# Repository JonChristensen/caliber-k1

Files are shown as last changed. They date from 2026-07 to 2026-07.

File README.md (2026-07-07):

# The Kelsus Manufacture — open-source, 3D-printable watch movements

**Nobody has published a working, printable, conventional watch movement designed
as a platform for complications. This project builds them — in public.**

The movements are the road, not the destination. The destination is two
complications that don't exist yet in mechanical horology:

1. **A haptic metronome** — taps your wrist at an adjustable musical tempo,
   powered by its own dedicated mainspring barrel (the architecture of
   mechanical alarm watches like the Vulcain Cricket, pointed at a new job).
   This is **Caliber K2**.
2. **A world-class tide indication** — going beyond every existing tide watch
   (Corum, IWC, CVDK all model a single tidal constituent) by mechanically
   summing a second constituent — the "priming and lagging" of the tides —
   plus perigean spring tides via an anomalistic-month cam.

Everything is **parametric Python ([build123d](https://github.com/gumyr/build123d))**:
the CAD is code, every dimension traces to a parameters file, every design
decision is a reviewable git diff, and geometry is unit-tested in CI before
any printer wastes plastic.

Like a real manufacture, this repo holds multiple calibers sharing one
engine (`movement/` — cycloidal gears, the sweep solver, the spring model):

| Caliber | What | Status |
|---|---|---|
| [**K1**](calibers/k1/) | Time + moon phase; the proven base movement | **First physical build underway** — rev C is printing; dry-train assembly next (PETG flexures to follow) |
| [**K2**](calibers/k2/) | Time + the haptic metronome | Two-sided layout frozen; winding link solved (log 0023); parts stage next |

Scale: these are desk-scale movements (Ø170 mm mainplate) — watch architecture
at a size FDM printing genuinely masters, with a metal-transferable topology
(K2's target is a 44×15 mm wristwatch case). Proven precedent: [Christoph
Laimer's printed tourbillon](https://www.thingiverse.com/thing:1249221)
(Ø102 mm, runs).

The ocean — the tide complication's destination — lives in the frame itself:
K1's train bridge is a breaking wave, and the wheels spin on whirlpool spokes.

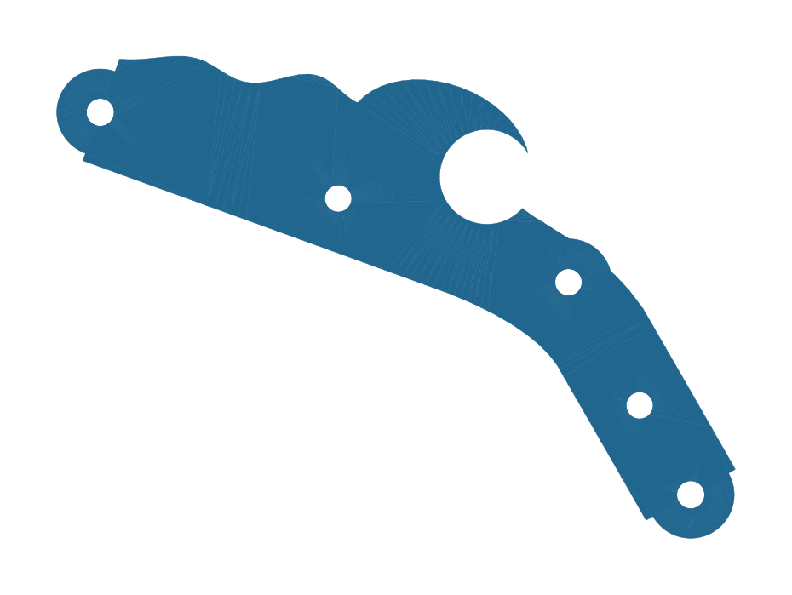
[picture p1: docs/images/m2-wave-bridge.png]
the wave bridge


## Build it

```bash
python3 -m venv .venv && .venv/bin/pip install -r requirements.txt
.venv/bin/python -m pytest tests/            # the geometry gate (runs in CI)
.venv/bin/python tools/export_print_kit.py   # K1 print kit -> exports/k1/print/
.venv/bin/python tools/render_previews.py    # PNG previews of every part
```

Print from [`exports/k1/print/`](exports/k1/print/MANIFEST.md): the MANIFEST
carries per-part orientation, support maps and quantities; the
[printing guide](docs/k1/printing-guide.md) carries the bench-proven Bambu
Studio settings. Curated, support-painted Bambu plates live in
[`exports/k1/print/plates/`](exports/k1/print/plates/README.md).

## Repository layout

- `movement/` — the shared engine: cycloidal gear generator, sweep solver,
  spring energy model. Caliber-agnostic by rule.
- `calibers/k1/` — Caliber K1 rev C: parameters, layout solver, parts, dial
  side, the traced wave bridge
- `calibers/k2/` — Caliber K2: frozen brief + metal target, the two-sided
  layout, the one-crown/two-position winding link
- `attic/` — superseded generations, kept buildable and tested: the rev A
  storey tower, the rev B flatten, K2's round-plate era
- `exports/` — print kits and review STEPs, per caliber (latest per line;
  history keeps the rest)
- `docs/log/` — the engineering journal (decisions and why), one unified
  timeline across calibers; `docs/k1/` — build guides, milestones, registers
- `tests/` — the geometry gate: clearances, mesh ratios, stack heights,
  assembled poses. CI runs it on every push.
- `tools/` — exporters and massing/review builders

## Licensing

Two permissive licenses, chosen so anyone can build a business on these
movements without asking us or paying us.

- **Hardware designs** (everything under `movement/`, `calibers/`, and
  `attic/`, plus the generated STEP/STL geometry):
  [CERN-OHL-P v2](LICENSE), the permissive variant of CERN's
  open hardware license. You can manufacture the movement, sell it, modify it,
  and keep your modifications closed. It carries an explicit patent grant, which
  a copyright-only license like CC0 or CC BY does not, and that grant is what
  protects a functional mechanical design. No reciprocity, no share-alike, no
  obligation to credit us on the movement.
- **Tooling** (`tools/`, CI): [MIT](LICENSE-MIT).

This is a deliberately more open position than the current open watch movement,
[openmovement's OM10](https://openmovement.org/project/om10/). The OM10 is
copyleft (CC BY-SA 3.0): it requires you to engrave its calibre number on the
movement, requires your derivatives to carry the same license, and reserves the
production 2D/3D data for sale under its own purchase terms. This manufacture
asks for none of that. Take the geometry, put it in a product, sell the
product, and you owe us nothing.

## Follow along

Build-in-public links (site, TikTok, videos) land here as they go live.

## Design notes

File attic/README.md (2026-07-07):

# The attic — superseded generations, kept buildable

Nothing in here is print-worthy; nothing in here is deletable. These are
the designs the current calibers were carved from, kept importable and
covered by the test suite so the record stays executable.

- **`reva/`** — K1's milestone-era storey tower (M1 going barrel → M5
  moon phase). Designed, probed, never printed as a whole: Jon's Fusion
  review flattened it into two-plate watch construction
  ([log 0009](../docs/log/0009-rev-b-architecture.md)). Its barrel frame
  (M1) WAS printed and bench-verified — the manufacture's first plastic.
- **`revb/`** — the first two-plate flatten. Every rev C part was ported
  from here ([log 0017](../docs/log/0017-rev-c-parts-port.md)); the
  print/metal variant switch it introduced now lives in
  `calibers/k1/variants.py`.
- **`k2_round_plate.py`** — K2's one-plate era: clock + metronome
  interleaved on a single round plate (massing r1–r5). The two-sided
  call ([log 0022](../docs/log/0022-k2-two-sided.md)) dissolved it.
- **`tools/`** — their exporters and mockups. `k2_massing.py` is
  stale-broken (r5-era globals) and kept only as the record of how
  `exports/k2/massing_r5.step` was made.

Old review STEPs were pruned from `exports/` (latest kept per line);
every pruned revision is in git history.

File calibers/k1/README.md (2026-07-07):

# Caliber K1 — time + moon phase (rev C)

The proven base movement of the manufacture: Ø170 two-plate construction,
6h going barrel → exactly-60-min center → 60s fourth → 30s escape (1 Hz
Swiss lever), indirect minute with a slip-collet hand-setting, moon train
on the dial side, and the traced-wave skeleton bridge as the show face.

**Status: first physical build underway (July 2026).** Mainplate, wave
bridge, barrel/winding group and the train + escapement set are printed;
dry-train assembly is next. The PETG flexures (mainspring, hairspring,
click, transfer pinion, stem clip) close the build after that.

## Where things are

- [`parameters.py`](parameters.py) — every dimension in the caliber
- [`revc.py`](revc.py) — the whole-movement model: z-grammar, layout
  solver, sweeps, the check_all gate (K1's binding of `movement.solver`)
- [`revc_parts.py`](revc_parts.py) / [`revc_dial.py`](revc_dial.py) /
  [`revc_dial_parts.py`](revc_dial_parts.py) — movement side and dial side
- [`variants.py`](variants.py) — the print/metal variant switch
  (`K1_VARIANT=metal` reflows the movement)
- [`gears.py`](gears.py) — TRAIN-default binding of the shared cycloidal
  engine

## Build artifacts

- Print kit: [`exports/k1/print/`](../../exports/k1/print/MANIFEST.md)
  (regenerate: `python tools/export_print_kit.py`)
- Printing guide: [`docs/k1/printing-guide.md`](../../docs/k1/printing-guide.md)
- Review STEP: `exports/k1/revc/movement_r11.step`
  (regenerate: `python tools/build_revc_movement.py`)

Earlier generations (the rev A storey tower, the rev B flatten) live in
[`attic/`](../../attic/) — buildable, tested, superseded.

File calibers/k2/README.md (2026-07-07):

# Caliber K2 — time + the haptic metronome

A TWO-BARREL caliber: K1's proven time core as the base, plus the
metronome as its complication — 60–180 BPM continuous (variable-inertia
balance with sliding weights), hammer tick + desk thump, chronograph
pen-cam pusher, its own barrel with a ≥30-min-at-180 beat budget.
The frozen brief is [log 0020](../../docs/log/0020-metronome-brief.md).

**Architecture of record: TWO-SIDED** (Jon's call, July 5 2026 — the
chronograph-module pattern). Base time movement on one plate, metronome
module stacked toward the caseback on its own full-diameter plate, both
Ø166. One crown, two positions: push winds the base, pull winds the
module through a riser + cross-plate transfer
([log 0023](../../docs/log/0023-k2-winding-link.md), SOLVED).

**The metal target governs**: K2 must eventually drop into a ~44×15 mm
wristwatch case (Ø40×10 movement). The print and the metal are one
topology at two scales.

## Where things are

- [`brief.py`](brief.py) — the frozen brief, metal target, energy
  budget, tooth counts
- [`layout.py`](layout.py) — the two-sided layout, module solve, Jon's
  full-cast inventory, K2's mesh-pair registry
- [`winding.py`](winding.py) — one crown / two positions: sweeps, solver,
  and the cross-plate gate

Massing artifact: `exports/k2/two_sided_r2.step`
(regenerate: `python tools/k2_two_sided_massing.py`).

**Status:** massing at Jon's gate; parts stage next. The superseded
one-plate interleave (massing r1–r5) is in
[`attic/k2_round_plate.py`](../../attic/k2_round_plate.py).

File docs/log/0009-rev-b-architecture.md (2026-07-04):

# 0009 — Caliber K1 rev B: the flattening (plan of record)

Jon's Fusion review of the rev A assembly found the truth: a 2.7:1 tower
built by accretion around the M1 test fixture. Rev B rebuilds the SKELETON,
keeps the ORGANS. Approved July 3, 2026.

## Architecture (classic two-plate watch construction)

- **Mainplate** Ø170 + individual **bridges** on top: barrel bridge, train
  bridge (THE WAVE — finally visible as the movement's crown), balance
  cock (jewel over the wave tube, per the 0003 contract, now on display).
- **All wheels interleave into 2-3 gear planes** between mainplate and
  bridges. Target overall height ~24mm => 4.2mm at Ø30 metal scale (OM10
  proportions). Every milestone gets a "would this ship in metal?" review.
- **Offset barrel** (not center). **Winding from the edge**: crown-style
  stem or edge key — never through the movement's face.
- **Center wheel at center** if spring physics allows a classic train;
  otherwise document the deviation as print-era with the metal train
  designed alongside (both ratio sets tested).
- **Escapement**: Swiss lever club-tooth as the DESIGN escapement (metal
  target); pin-pallet kept as the printable fallback variant. Both from
  one parametric generator, selected by a parameter.
- **Display**: hands on the front at proper heights (no storeys), moon
  aperture in a dial sector. Module bay preserved (interface v0 carries).

## What transfers unchanged (the organs)

gears.py (cycloidal generator) - decor.py (wave, swirls, tube contract) -
tools/solve_m4.py pattern (extend into a general placement solver) -
oscillator physics + trim math - moon train (14->63|8->105) - module
interface contract - all test discipline - Milestone 1 barrel INTERNALS
(spring, arbor, ratchet, click — the drum becomes offset).

## What dies

The spider plate (test fixture, never architecture). The deck plate, dial
cock, and storey stack. Center-through winding square + knob. The M1
stand plates remain only as the historical barrel test rig.

## Execution order

1. rev-b/ layout: gear-plane assignment + solver run for the full flat
   train (barrel, center, W3, W4, escape, balance, motion works UNDER
   the dial side — the watch way).
2. Mainplate + bridges (wave bridge = train bridge, visible).
3. Escapement generator (lever variant) + balance over the wave.
4. Motion works + hands + moon module in-plane.
5. Renders reviewed in Fusion BEFORE each milestone freezes.

## Status correction (Jon's catch, post-2e-half)

r6 has NO pallet lever — "mechanically complete" was an overclaim. Built
and verified: full going train (phase-aligned mesh proofs), pallet cock,
pallet arbor layout + pins, balance staff/ring/hairspring seats. Missing:
the lever itself (rev A's is welded to tower geometry) and the roller's
rev B seat. Escapement remains variant-triggered per the plan:
print=pin_pallet (tolerance-tolerant, proves the runner), metal=
swiss_lever club-tooth (DFM pass, machining tolerances) — including the
matching escape-wheel pair (pointed vs club teeth). Next mechanical work:
port the pin-pallet lever + roller onto escapement_layout_b.

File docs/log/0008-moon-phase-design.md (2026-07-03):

# 0008 — Moon phase: drive point found, storey decision pending

Findings from M5 geometry kickoff:

1. **M4 bug found & fixed**: the hour wheel's Ø9 pipe collided with the
   dial cock's Ø6.4 bore. Cock bore opened to Ø9.4 — the pipe now journals
   in the cock (a feature: extra hour-wheel steadiness). Hands stack shifts
   up ~3mm in the next export pass.
2. **Moon drive**: a 14-leaf pinion integral with the hour pipe, ABOVE the
   cock (z~56+, open sky). The committed 46/9x104/9 ratios assumed a 9-leaf
   pinion that cannot exist on a Ø6.8-bore pipe (zero root depth) — ratios
   must be re-searched with s1_pinion=14 (target (A/14)(C/d) = 59.061176).
3. **Moon train runs module 0.8** (display torque only): the 104t-class
   moon disc shrinks to ~Ø85, which fits the rim with center <= r40.
4. **Open decision**: the moon disc plane vs hands sweep — either the disc
   flies above the minute hand (tower grows ~5mm) or the classic move: a
   fixed DIAL ring over the works with the double-hump moon aperture, hands
   above the dial. The dial option is more watch, less tower. Recommended.

Next: re-run ratio search (s1=14), model disc + s1 arbor + moon cock +
aperture dial, module clearance tests. The module mounts on the dial cock
+ one deck pillar — the module bay's first tenant.

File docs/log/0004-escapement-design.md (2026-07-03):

# 0004 — Milestone 3: the escapement storey

Pin-pallet lever escapement above the wave bridge; balance centered on the
wave tube per the 0003 contract. Key numbers: pallet arbor 16.5mm from the
escape arbor (pins subtend 3.5 tooth spaces, engage 1.6mm); fork 20.7mm;
balance Ø50 at 1 Hz; hairspring 11 coils × 0.45mm PLA, predicted T=1.037s.
Physics lives in parameters.py (balance_inertia, hairspring_stiffness,
predicted_period) — CI fails if the oscillator drifts out of the nut-trim
band. Plate grew to Ø170. Platform stands on two plate-rooted pillars after
the clearance test caught bridge-mounted legs inside the escape wheel sweep
(center-distance checks lie; radii matter).

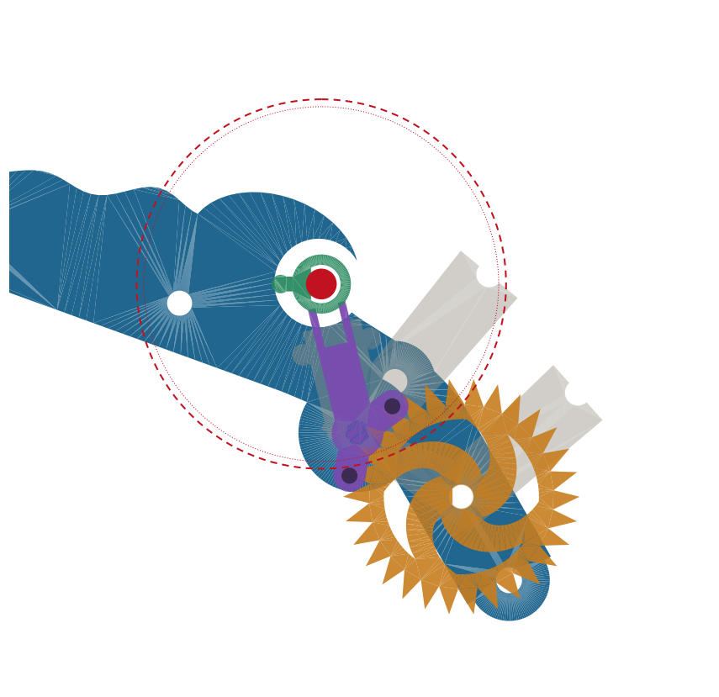
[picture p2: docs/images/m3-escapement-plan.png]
escapement plan


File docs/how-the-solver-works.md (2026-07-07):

# How the rev C layout solver works

*(Plain-English companion to `caliber_k1/revc.py` — the code is ~80 lines;
this is the idea behind them.)*

The solver in three pictures

## The trick that makes it all possible: forget the tooth shapes

A gear is a complicated shape, but the moment it *spins*, it occupies a
simple cylinder — a can. So the solver never looks at teeth at all. Each
part becomes five numbers: where it sits (x, y), how fat it is (radius),
and which heights it spans (bottom z, top z). That's a `Sweep` — the whole
movement is about twenty cans.

The payoff is that "do these two parts ever touch, at any rotation, at any
moment?" collapses to grade-school math: **if two cans share any height,
the distance between their centers must beat the sum of their radii plus
2mm of air.** Distance between centers is the Pythagorean theorem. One
subtraction, one square root — millions of checks per second, where asking
the CAD kernel to intersect two toothed solids takes about a second each.

## Two escape hatches make it a watch instead of a parking lot

1. **Gears that are *supposed* to touch** (meshing pairs) are on a
   whitelist — the can test skips them, and their tooth-by-tooth
   engagement is proven later by the slow, accurate CAD probes
   (`tests/test_revc_parts.py`), run once instead of millions of times.
2. **Cans only conflict if they share height** — the shelf system. The 80t
   minute wheel flies right over the barrel because it's on shelf B and
   the drum tops out below it. Watchmakers have exploited this for three
   centuries; the solver gets it as a rule.

## The search is a compass walk

Meshing gears must sit at an *exact* center distance — the minute wheel
belongs precisely 35mm from the barrel. So its position isn't free; it's
somewhere on a circle. The solver puts the barrel down, swings a compass
around it, and tries 36 spots (every 10°). Each survivor gets a new
compass swung around *it* for the next wheel, and so on down the chain:
barrel → minute → third → fourth → escape → balance. Six nested compasses.

## Pruning is why it finishes before we retire

Naively that's 36⁵ ≈ sixty million layouts. But the moment a candidate
spot crashes into anything already placed, the solver abandons it **and
every layout that would have been built on top of it** — millions of dead
branches lopped off with one failed subtraction. It's how you solve a
maze: you don't map the whole dead end, you turn around at the wall.
Survivors get scored, and the winner is the layout whose farthest part
edge stays closest to center — the most compact watch that breaks no rules.

## The one weakness — and it bit us twice

The solver only knows what the cans tell it. The pallet fork isn't
remotely can-shaped (it's a rocking arm), so we approximate it with two
circles covering its full swing. When those circles were drawn too small,
the solver cheerfully approved layouts where the *real* fork poked into
the *real* plate. Both "unsolvable!" panics and one genuine collision in
this project traced to dishonest cans — never to bad math.

That's why the pipeline is belt-and-suspenders:

| stage | speed | what it proves |
|---|---|---|
| can test (`check_all`) | millions/sec | placement never collides, at any rotation |
| tooth probes (phase-aligned) | ~1 sec each | meshing gears engage without jamming |
| assembled-pose gates | ~30 sec total | the exported STEP itself is clean |

The cans buy speed; the probes keep them honest.

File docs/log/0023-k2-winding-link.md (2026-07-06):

# 0023 — K2 winding link: one crown, two positions across two plates

**Date:** 2026-07-05 · **Status:** open design problem, scoped

Two-sided K2 (log 0022) leaves one real sub-design: how one crown winds
**both** barrels when they sit on different plates. Position 1 (push)
winds the base barrel via K1's existing winding — reused, done. Position
2 (pull) must wind the **module** barrel, and that's the hard part.

## The constraint the gate surfaced

The module barrel is big (76t, r38) and central, so its ratchet sits at
the module-plate **center**, at bridge z (~34–36). Reaching it from a
base-level north crown is NOT a straight shot:

1. stem enters the north rim at base level (z~13)
2. a **vertical riser** climbs ~22mm to module-bridge level — and must
   clear both drums (r38), so it rides the **flank** of the module drum
   (there's only 9mm north of the drum, but 48mm+ to the sides/south)
3. a **horizontal transfer wheel** at module-bridge level runs inward
4. → the module crown wheel → the module ratchet

Plus the shared clutch + setting lever + detent that select position 1
vs 2. First naive hand-placement collided (riser through the drum, clutch
crammed north) — a clear sign this needs its own solve, not patching.

## Plan

A small dedicated solver for the winding link: riser azimuth free around
the drum flank, transfer-wheel placement gated against the module train,
clutch works spaced along the stem. Reserved coarsely now
(`winding_link_zone`) so the massing shows the space; geometry at the
solve. Everything else on the module plate is gated clean.

## Update (same day): position 2 SOLVED

A focused `solve_winding_link` (search the riser azimuth for a channel
clear of both drums, place the module crown wheel on the line to the
ratchet, transfer + clutch). First objective (minimize plate reach)
threaded a 70mm train up the south channel — valid but absurd. Re-aimed
at **shortest winding path**: found the NE flank, **44.5mm**, one crown
at ~2 o'clock → riser (40.9, 50.5) up the drum flank → transfer →
module crown wheel (19.9, 41.5) → module ratchet. Clean against both
plates (`k2_winding_gate`, `test_k2_winding_position2_clean`).

Key fix: the keyless cluster (clutch/setting/detent/riser) interlocks —
the 2mm inter-part rule is wrong for a coupled mechanism, so those pairs
are whitelisted (verified by the part-level probe later, like the
escapement).

**Position 1 (base) remains:** winding the base barrel from the same NE
crown needs a multi-wheel base-level train that dodges K1's SE click
(the short paths collide). Pending tier: `cw1_core`, `m_stem`,
`wind_base`, `wind_xfer_base`. Not the novel part — ordinary keyless
routing — but real, and left honest rather than faked.

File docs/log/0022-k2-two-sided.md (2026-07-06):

# 0022 — K2 goes two-sided: the plate stops growing

**Date:** 2026-07-05 · **Decision:** Jon — "two-sided metal module."

Jon chose the chronograph-module architecture: base time movement +
metronome MODULE stacked toward the caseback, not side-by-side on one
plate. This **dissolves the O250 frankenplate problem** — the two
movements no longer compete for one plane, so each gets its own
full-diameter plate. K2's plate returns to **Ø166 (same as K1)**.

## The stack (front → back)

crystal · dial + hands · motion works · **base plate** · base going
train + escapement + balance + base bridge · **module plate** ·
metronome works + hammer + variable-inertia balance · module bridge ·
display-back crystal.

- **BASE** = K1's proven time core (revc) verbatim, minus the moon train.
  No re-solve — it's K1.
- **MODULE** = the metronome ALONE on its own Ø166 plate. Solved
  (`solve_module_alone`, 123s) to reach 63.8 of 83 — 19 mm of margin, a
  roomy single-cluster layout like K1's clock, not a desperate interleave.
- One crown, two positions winds the two barrels (push = base, pull =
  module).

## Numbers

Print: Ø166 × ~36 mm (two movements stacked — a tall desk model, fine).
Metal: Ø40 × ~6 mm scaled, but the z-table is variant-tall → fits the
~10 mm case budget with room. The metronome, its balance and hammer,
show through the sapphire display back.

## Status

`k2_module_gate` CLEAN; the full inventory (log 0021) rides the module
plate. Next: the base↔module winding link (one crown, two positions),
the module-plate pillars down to the base, and Jon's massing gate on the
two-sided stack. Then K2 parts — the variable-inertia balance and hammer
first (the two mechanisms K1 doesn't already prove).

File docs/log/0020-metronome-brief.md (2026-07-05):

# 0020 — M6 brief: the haptic metronome module

**Date:** 2026-07-05 · **Status:** requirements frozen (Jon), mechanism
concept chosen; massing + solve next

## Jon's requirements

- **Tempo: 60–180 BPM, continuously adjustable** (3:1 range)
- **Beat: hammer tick + desk thump** — hear it AND feel it through the desk
- **Start/stop: chronograph-style pusher** — press to run, press to stop
- Own barrel (independent of the timekeeping train), winds like the clock

## The mechanism concept

**A variable-inertia balance.** The movement lies flat, so gravity
pendulums (Maelzel-style) are out — the oscillator must be a balance +
hairspring, which is orientation-free. The 3:1 tempo range is the hard
part: rate ∝ √(k/I), so a 3:1 rate span needs a **9:1 inertia span** —
far beyond regulator pins. The answer is horologically delicious: **two
weights sliding radially in the balance arms** (r≈5→15mm gives the ~9:1
on the dominant inertia term), driven symmetrically by a lead screw or
scroll cam through the **tempo knob**. A Gyromax taken to its logical
extreme — the tempo dial literally moves the balance's mass outward for
largo, inward for presto.

- Oscillator: 0.5–1.5 Hz (beat = 2/period = 60–180 BPM)
- Escapement: our proven club wheel + Swiss lever, module-scaled
- **Hammer**: pin wheel on the escape arbor lifts a weighted hammer that
  drops on the mainplate/base — one strike per beat, tick + thump
- **Pusher**: pen-cam (retractable-ballpoint) two-state toggle pressing a
  brake finger onto the balance rim; press-run, press-stop
- Tempo calibration: engraved BPM arc under the knob, bench-calibrated

## Reality check on space

The reserved module bay (r18 at (56,18)) holds a barrel OR the
oscillator, not both plus a hammer and pusher. Expect the module to
claim the whole eastern sector, possibly as its own **module plate**
above the bridge band (the massing will decide honestly). The module
interface (0004) still governs: the metronome must mount/dismount as a
unit.

## Next steps (massing-first, as always)

1. Station list + sweeps: m-barrel, m-train (2 wheels), variable
   balance (its sweep grows with the weights OUT), lever, hammer arc,
   pusher line, tempo knob.
2. Energy model: beat torque for an audible strike × runtime target
   (≥30 min practice session per wind? Jon to confirm).
3. Solve the module layout in/over the east sector; massing render;
   Jon's gate; then parts.

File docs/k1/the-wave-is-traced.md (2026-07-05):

# The wave, traced

The bridge decoration is TRACED from `art/wave_reference.png` (Jon's
mockup), not hand-drawn. Pipeline: `tools/trace_wave.py` classifies the
image into blue-plate / white-gap / gray-rim, finds the disc, and turns
each white wave-gap into a millimetre polygon in `art/wave_traced.py`.
`revc_parts.traced_wave_faces()` subtracts those polygons from the bridge
with structural keep-outs removed first, so the art can never cut a
load-bearing feature.

## To change the wave
1. Edit the mockup image (any tool), keep it a blue plate with white
   wave-gaps and a gray rim, save over `art/wave_reference.png`.
2. `PYTHONPATH=. .venv/bin/python tools/trace_wave.py [rotate_deg]`
3. Rebuild — the new curves flow straight through to the STL.

An SVG-path pipeline (draw the curves directly in a vector tool) is a
small addition if pixel-tracing ever loses fidelity.

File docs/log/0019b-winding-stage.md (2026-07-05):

# 0020 — The winding stage: crown to ratchet, nothing above the bridge

**Date:** 2026-07-04 · **Status:** movement_r5.step (40 components), 82 green

Jon's massing r6 gate passed and the winding parts landed. The mechanism
settled one level simpler than the massing sketched: no tall-core crown
wheel — the 6498-true arrangement cuts 23 bevel slots into the crown
wheel's UNDERSIDE and the stem's 7t pinion meshes them FROM BELOW (rev
B's proven face-slot pair, flipped: the height cost becomes a height
savings). Stem axis z12.8 in the corridor; the crown never rises above
the bridge; the drum_gear x stem whitelist is justified by an analytic
clearance test (pinion swept cylinder to drum tooth tips: 2.85 >= 2.0).

Parts: crown_wheel_c (24t spur + underside slots, flush in the bridge
pocket), crown_stud_c (shoulder stud, press tail in the web),
stem_c (one print: fluted crown, tunnel body, clip groove, pinion),
stem_clip_c (printed C-clip). Bridge grew the crown pocket + stud bore
+ the tunnel boss (case-tube analog). The slot ring spans the pinion
tip's full chord (first cut grazed solid wheel beyond short slots —
the engagement-profile probe found it: 0 at settled roll, 1.4 mid-rib).

Winding: ~9 crown turns for the full ~17h wind (23/7 x 24/24 x 2.78
turns). Setting: still push-the-hands (transfer collet slips); the
pull-to-set clutch is the future keyless refinement, and the stem is
now at the right level for it.

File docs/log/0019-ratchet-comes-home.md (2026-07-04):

# 0019 — The ratchet comes home: Jon's NH35 catch re-solves the movement

**Date:** 2026-07-04 · **Status:** massing_r4 + movement_r3 exported, 80
tests green, verification-fleet findings applied

Jon flagged the dial-side ratchet poking into the dial's airspace and held
up the NH35: the ratchet belongs on the MOVEMENT side. He was right, and
the diagnosis went deep: the dial-side winding was a patch on a patch —
the 80t minute wheel overhung the barrel center, which decapitated the
barrel arbor at z11, which forced the hanging barrel, which forced
dial-side winding.

## The root fix: new tooth counts

`(60, 10, 56, 7, 45, 6, 36, 18)` — worked out under four simultaneous
constraints (all now encoded in the solver's menu comment):

- minute wheel ≤ r29 so the **barrel arbor column** (a new permanent
  sweep the global gate protects) rises past plane B to the bridge;
- minute PINION small enough that it clears the coplanar third wheel —
  which forced the drum to 60t/10-leaf = **6h per turn**, and the bigger
  drum holds more spring: runtime IMPROVES to **~17h** (from ~10);
- the barrel stands off at y ≥ 40 (a dial-side reservation: the moon
  pinion's pocket needs 10.7 of drum-free plan at the origin);
- (56/7)(45/6) = 60.000 — timekeeping exact, as always.

## What the architecture becomes

- **Two-bearing barrel**: plate cup below, bridge-web bearing above. The
  hanging-barrel wobble flag from 0017 dies.
- **Ratchet + click recessed FLUSH in the bridge top** (the NH35
  composition), click pegs through the bridge web, winding by key into a
  **female square socket** — nothing stands above z17.7.
- **The dial face is completely untouched** — no bore, no boss, no pegs.
  The dial sheet reservation is now a constant (`DIAL_SHEET`).
- Transfer chain slimmed to 10-24-24-10 (the pinion pocket must fit
  between the minute arbor and the drum recess — 0.8mm of margin).

Both solvers re-ran (bridge 70s, dial <1s after teaching the i2 ring to
walk at 1/3 step — its legal windows are ~7° wide). Same-day fleet
findings folded in: feature-aware post bores (the disc post would have
breached the bay floor — posts are now IN the gate), posts extended to
z-0.7 as platform supports/locators (dial-feet analog), cannon/hour pipe
walls thickened, the transfer collet got a doubled flexure hub, press
bores derive from `Variant.press_r`, and a platform-coverage retention
test. Interim hand-setting: push the minute hand; the transfer collet
slips (the keyless stage adds the proper setting path).

## For Jon's gate

`exports/revc/massing_r4.step` (composition moved: train now sweeps the
WEST side, balance at ~5 o'clock, moon window lands near 6) and
`exports/revc/movement_r3.step` (36 components). The stack still tops at
17.7; the dial side is clean glass.

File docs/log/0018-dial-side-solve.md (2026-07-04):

# 0018 — The dial side: four depth bands, three hard theorems, one solver

**Date:** 2026-07-04 · **Status:** movement_r2.step (36 components), 79 tests
green, dial verification fleet run before Jon's gate

The dial side got the same treatment as the massing: a whole-face model and
solver (`caliber_k1/revc_dial.py`) BEFORE any geometry, because rev C's
compactness makes the plate's underside a minefield — the drum recess floor
sits 2.2 above the dial face with its plan edge 12mm from center, the bay
allows 2.8, bushings 2.9, strap pilots 1.9. Every pocket obeys
`depth ≤ local ceiling − 0.6`, enforced by `check_dial()` forever.

## Three theorems the solve surfaced

1. **The 1:1 transfer can't be a pair.** A direct pair needs two r13+
   wheels; the cannon-side one would overhang the drum plan where only 1.6
   of depth exists. It became a 16-24-24-16 **idler chain** — every member
   deep-band legal, and the odd mesh count keeps the hands clockwise (the
   full chirality chain from the club-tooth lean to the cannon is documented
   in the module docstring).
2. **The axis theorem.** The hour pipe surrounds the cannon, so the cannon's
   gears must sit ABOVE the hour pipe's top. That forces a SHORT hour pipe
   with the moon pinion riding LOW (B2) — which also dissolved the
   motion-wheel/moon-wheel fight for the southwest plate.
3. **A two-stage moon train is impossible here.** Any wheel meshing a pinion
   at the origin lands its rim at d/(1+ratio) from center; the cannon needs
   7.8 clear, and 59.0625 split two ways forces ratio ≥ 4.2 → rim at ~4.
   (Rev B carried this collision silently — the gate caught it.) The moon is
   now THREE gentle stages: (36/24)(54/12)(70/8) = 59.0625 exactly, still
   29.53125 days, 1 day per ~122 years.

## What's in the face (frozen `DIAL_LAYOUT`, reach 64.3 of 83)

Motion works south (12:1 exact, module trick at d=24); moon train sweeping
west, disc at 10–11 o'clock with the platform window over its r13.5 orbit;
transfer chain in the western corridor. Parts: Ø3 center post + five Ø2
arbor posts (register pins), cannon, hour wheel + integral moon pinion,
motion arbor, w1, w2, moon disc (moons recessed 0.25), wheel-form idlers
(pinion-form idlers only kissed noses — proper cycloidal pairing is
wheel-drives-pinion), and the retaining platform.

## Design corrections the gates forced

- **Backlash scales with module** (0.3·m): the flat 0.3 tuned for m1 train
  teeth would eat half a m0.6 tooth.
- **Hand setting**: the chain rigidly geared the cannon to the train — no
  way to set the time. The transfer pinion now friction-grips the minute
  arbor's round stub via a slit collet (the hairspring pattern): running
  torque carries, setting torque slips. The keyless stage builds the
  setting input on top of this slip.

## Open items

- Keyless works (winding conversion from the dial-side square + setting).
- The wave pass (2f) over the now-complete movement.
- Metal-variant escapement retune (tracked skip, see 0017).

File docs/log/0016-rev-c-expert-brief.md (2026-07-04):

# 0016 — Rev C: the expert brief (end of the patch loop)

Jon's diagnosis, accepted: rev B was rebuilt by accretion under user
correction — locally-right patches, globally-wrong architecture. Rev C
is designed top-down, whole-movement-first, by the numbers below.
No part gets modeled until the layout study passes the global test.

## Hard targets (print variant / metal variant)
- Total stack **<= 28mm / <= 14mm** including cock, excluding crown.
- **Two gear planes + one escapement plane.** No arbor longer than 18mm.
- Drum **<= 35% of plate diameter** (<= O60 on O170). Recover energy by
  wider-flatter spring or accept 4-6h print runtime (bench duty).
- Barrel position becomes a FREE variable in the layout solve: if the
  drum cannot coexist with a central center wheel, use an intermediate
  transmission wheel (classic solution) or offset time display.
- Stem at PLATE level; true keyless works (winding pinion, clutch,
  setting lever, yoke) in the dial-side pocket; crown fully outside the
  plate boundary. Crown wheel + ratchet stay celebrated on the bridge.
- Oscillator: Jon's arrangement is KEPT (it converged on real watch
  practice): ring under bridge in the well, spring nested in the well
  thickness, near-coplanar cock, removable pallet bridge, steel staff,
  bushings/thrust shims per the parts register; jewels in metal variant.
- ONE broad bridge (the wave) + balance cock + pallet bridge. Nothing else.

## Process discipline (the actual fix)
1. **Global swept-volume test FIRST**: every rotating part declares its
   swept cylinder (r_tip, z-band); one test asserts all pairwise
   rotating-vs-rotating and rotating-vs-static clearances across the
   WHOLE movement. It exists before any rev C part is modeled and gates
   every commit. No more pairwise patches.
2. Layout study: solver over ALL stations simultaneously (barrel free,
   train, oscillator, keyless, motion works) against the swept-volume
   model + energy model. Deliverable: one massing STEP for Jon's gate.
3. Only after the massing gate: port parts (all generators survive).
4. Jon's role returns to taste and bench truth; whole-movement
   consistency is the designer's job — mine — enforced by the global
   test, not by his screenshots.

Rev B stays in-tree: every generator, probe, register, and lesson
carries forward. The layout does not.

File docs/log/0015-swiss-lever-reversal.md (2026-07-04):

# 0015 — The Swiss lever reversal (Jon's AliExpress evidence)

Jon gently pushed back on "a Swiss lever can't print": his AliExpress
tourbillon visibly has a pallet fork. Verified — he is right:

- Laimer (thing:1249221, our scale ancestor): "The watch has a Swiss
  lever escapement." Anchor 100% printed PLA (0.06mm layers, 80% infill),
  no jewels, runs at Ø100mm — smaller than K1.
- The Mechanica clone family (Jon's unit): printed "Escape Fork" with
  named left/right pallets; runs; known overbanking mode fixed by longer
  fork horns (designer ships a tuning variant + STP).
- Design rules (Headrick/abbeyclock, NAWCC, funprints4u): LOCK 2-3 deg
  for print (+-0.15mm error ~ 1 deg of lock at Ø32 wheel; watch practice
  1-2 deg eaten entirely by print error), DRAW textbook 12-15 deg (no
  more — unlocking losses), flat faces, generous horns, banking pins.

## Decision

Escapement PARITY: swiss_lever in BOTH variants — angles per variant
(print: lock 3.0/draw 15.0; metal: 1.5/13.0). Pin-pallet demoted to
fallback (code retained). The print bench now rehearses the metal
escapement's architecture — the variant switch fulfilling its purpose.
Next build session: parametric lever generator (lock/draw/lift from the
variant), club-tooth escape wheel pair, fork horns sized per the
Mechanica overbanking lesson, phase-aligned probe like the train's.

Full sources in the research transcript; key: makezine tourbillon
tutorial, thingiverse 1249221, myminifactory Mechanica guide,
abbeyclock lever construction.

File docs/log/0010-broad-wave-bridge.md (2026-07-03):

# 0010 — The broad wave bridge (Jon's NH35 correction)

Vocabulary bug found by Jon: "bridge" meant a narrow finger bridge to me,
but the NH35-style BROAD train/barrel bridge to him — the wide decorated
plate that covers the movement's back and defines its face. He is right:
that is the showpiece, and it is also better engineering.

## Revised step 2b (supersedes the narrow band bridge)

- ONE broad bridge covers barrel + train: upper bearings for barrel,
  center, third, fourth, escape in a single plate (z16-19). Replaces
  three planned parts. Feet become a bolted perimeter, NH35-style.
- Large round BALANCE OPENING (~Ø54): the balance swims visible in its
  own well; balance cock spans the opening; staff upper bearing + cap
  jewel in the cock. The enclosed-tube-as-bearing idea is retired — the
  open-mouthed rev A curl returns at the opening's rim.
- Art direction (Jon): the crest breaks AWAY from the balance — the
  balance emerges from the wave into calm water. Serenity over drama.
- Surface finishing pass later: printed Cotes de Geneve — literal
  "Geneva waves" striping flowing in the swell direction.
- The narrow wave_bridge_b stays in git history as a study.

Inspection gate for the rebuild: exports/revb/wave_bridge.step over the
massing — swells legible at arm's length, curl open at the balance well,
five bearing bosses over their arbors, stem sector untouched.

## Print-vs-metal deviation register (running)

- Stem line at z29.5: forced by the 20.5mm printed drum the stem must
  overfly. Metal variant: ~5mm barrel, stem drops to plate level
  (NH35-style). Crown moved to r88, overhanging the plate edge with
  >=0.5mm proven clearance to the bridge's north edge.

## 0012-in-place: the variant switch (Jon's clean-flip requirement)

Variant is now a first-class build parameter (revb.VARIANTS, K1_VARIANT
env): print and metal share every coordinate and tooth count; they
differ only in dimension TABLES (drum height, clearances, spring,
escapement type), and derived values like the stem line are FORMULAS
of the variant — flip the switch, the movement reflows. Migration plan:
every part function gains variant-awareness as it is next touched; CI
will build and test BOTH variants; exports split into
exports/revb/{print,metal}/. The CNC drawing will be the metal variant
of the same tested code — never a translation.

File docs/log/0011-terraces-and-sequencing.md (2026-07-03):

# 0011 — NH35 bridge study: terraced relief + design-the-cover-last

Jon supplied the isolated NH35 decorative bridge. Two adopted lessons:

1. **The wave should be TERRACED, not outlined.** The NH35's waves are
   stepped crescent plateaus in z — light catches each step edge. Rev B
   swells become three relief terraces (~1mm steps) cascading toward the
   balance well; the crest is the tallest terrace curling at the rim;
   the well may open into a C like the NH35's. Sunburst/Geneva graining
   flows across terraces in the finishing pass. Prints and mills cleanly.

2. **Sequence: pack the movement first, sculpt the cover last.** The
   bridge's mechanical interfaces are frozen and tested (5 bearings,
   well, feet). Its OUTLINE and terracing wait until everything under
   it exists: balance cock, escapement, keyless works, dial-side moon.
   Revised order: 2c balance cock + escapement -> 2d keyless works ->
   2e motion works + moon (dial side) -> 2f THE BRIDGE beauty pass with
   the full movement packed -> Jon's gate on the complete composition.

## Correction (same day, Jon's second photo)

The NH35 bridge is NOT terraced — it is a FLAT plate. The "steps" were
Cotes de Geneve striping (sub-mm surface finishing) whose grain-direction
changes read as depth in the first photo. Revised guidance for 2f:

- The plate stays flat (simpler to print, simpler to mill — and true to
  the reference). The wave lives in (a) the sculpted OUTLINE and
  cutouts, and (b) shallow striping: ~0.3mm printed relief bands
  (one layer step) flowing as wave-front crescents toward the well —
  our Cotes de Geneve, literally waves.
- Real z-terracing remains available as a deliberate K1 signature move,
  but it must be chosen as OUR aesthetic, not misattributed to the
  NH35. Decision deferred to the 2f beauty pass with the movement packed.
- Sequencing lesson (pack first, sculpt the cover last) stands unchanged.

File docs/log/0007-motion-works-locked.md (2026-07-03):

# 0007 — M4 layout locked: every arbor placed, every clearance tested

Final restack after tests caught two more real collisions (R1's Ø34 wheel
cannot pass the foot_a/cock gap — max gap supports Ø26; first R2 branch sat
in the winding-knob sweep and balance ring):

- Ratios: (24/16)(32/10)(30/10) = 14.4 exact; 12:1 motion works. Tested.
- R1 24t at (-9.65,-58.23) z10.5-15.5, climbing pinion to the deck.
- R2 32t at (11.27,-56.49) — computed circle intersection, outboard branch.
- T (dial center) at (14.8,-36.8); M at (38.8,-36.8); hands at z56.
- Deck plate z28.2 on pillars (57,-17) and (2,-79); dial cock z52.5.
- CONSEQUENCE: the T-handle winding key is retired; M5 models a low-profile
  winding KNOB (Ø44, sweep r<=23.5 enforced in test_m4_deck_clearances).

Remaining M4 modeling (no unknowns): r1/r2/t/m arbors, deck plate, dial
cock, friction cannon, hands, knob — next session, then M4 prints.

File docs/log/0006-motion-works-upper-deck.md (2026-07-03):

# 0006 — Motion works: the upper-deck solution

The placement solver (tools/solve_m4.py) proved option B's ground-floor
walk IMPOSSIBLE: at z0-16 the annulus r51.5-68 is corked at every azimuth
(foot_a az283, stand pillar az305.7, foot_b az182, cock/escapement
az200-260). No idler chain of any length fits. Negative result, exhaustive.

## The solution: climb, then walk (hybrid of options A and B)

- R1 (32t, L2 z10.5-15.5) meshes W1's second pinion at the VERIFIED spot
  (-9.9, -62.65): r63.4 — outside the spider disc (r50), beside the
  bridge band (18.4mm > 14 needed), clear of the cock column (21mm).
- R1's 10-leaf pinion rides a TALL shaft up to z27-32 — climbing past
  the bridge level in open air.
- Above z28 the ENTIRE plate is open except: cock column (az249 r78.5),
  winding click (r~34, z28.3-33.3), ratchet (r20), balance ring (r25
  about az229, z35+), escapement platform (az200-250, z31-34), key sweep
  (z38+ center). The az 300 -> 110 fairway is completely clear.
- R2 (24t wheel z28-33, 10-leaf pinion above) -> T (30t) lands in the
  open sector az~60 at r~55; 12:1 motion works + friction cannon + hands
  stack above; subdial ring prints as part of a small "dial cock" bridged
  off the spider rim + one plate pillar.
- Ratios unchanged: (32/16)(24/10)(30/10) = 14.4 exact; MOTION dataclass
  needs amending from the committed 2-stage to this 3-stage (same test).

The time literally rises out of the movement and floats on the top deck,
wave on the left, dial on the right — regulator layout in 3 storeys.
Next session: model r1/r2/t arbors, dial cock, hands, friction cannon;
solver extends trivially for the upper deck if placement needs tuning.

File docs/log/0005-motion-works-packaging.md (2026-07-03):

# 0005 — Motion works packaging: the constraint map

Placing R/T/M arbors is the tightest packaging problem in K1. Verified
no-go results (each caught by clearance math before printing anything):

1. Ø48 R-wheel at deck level (z0.5-5.5, meshing W1's pinion): needs
   |R| >= 63.5 (drum) but <= 58 (rim). Contradiction — impossible.
2. Ø72 T-wheel anywhere: below z22.3 blocked by drum (needs |T|>=75.5),
   z22.8-27.8 blocked by spider disc, z28-33 blocked by ratchet sweep
   (needs |T|>=58.5 but rim caps at 46). No legal storey exists.
3. Three-stage 2 x 2.4 x 3 chain (32/16 -> 24/10 -> 30/10 = 14.4): R1 at
   (-9.9,-62.7) z10.5-15.5 works (clears cock foot via z, foot_a by 2.3mm),
   but R2 at z16-21 fouls either the drum annulus (<51.5) or the wave
   bridge band near W1. Restacking R2 lower collides with W1's own wheel.

## The open z-storeys (rel. plate top)
- z0.5-16.5: outboard annulus r51.5..(83-tip) only — narrow but real
- z >= 33.5, r <= 37.5: above ratchet, inside spider footprint — OPEN
  and unused. Candidate: run the time display UPWARD at the center —
  a "mystery-dial" storey above the ratchet, driven by a tall lateral
  idler from R1's level through the spider's window gaps (the spider is
  3 spokes; its windows are open shafts from z22.8 up).
- The 65.7-azimuth third of the plate is empty at ALL levels below 22
  outside r44 — but unreachable in one 24mm hop from W1; needs an idler.

Next session: solve with either (a) the center mystery-dial storey via a
spider-window idler, or (b) two idlers marching az 245 -> 65 around the
rim annulus at z10.5-15.5. Ratios stay as committed (14.4 x 12 exact).

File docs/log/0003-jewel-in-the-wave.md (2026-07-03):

# 0003 — The jewel lives in the barrel of the wave

Jon asked whether the balance jewel would sit in the middle of the breaking
wave on the train bridge. It hadn't been planned — but the geometry already
agreed: the wave's tube center sits 34.5 mm from the escape arbor, and a
module-1, 30-tooth escape wheel wants its balance center at 30–36 mm
(2.0–2.4x escape pitch radius). The tube IS a balance seat.

So it's now a design contract, not a coincidence:
- `decor.wave_tube_center()` exposes the seat position.
- `test_wave_tube_is_a_balance_seat` fails any future layout change that
  pulls the tube out of lever-escapement reach.

Milestone 3 implications:
- Balance (Ø~50, 1 Hz) centered on the tube; wheel sweeps over the crest.
- Lower pivot bearing: a small chaton set in the tube, held from beneath
  the bridge so the wave's mouth stays visually open around it. The
  "jewel" itself can be a 4 mm red glass cabochon (or printed red cap) —
  the pearl in the wave.
- Plate grows Ø150 -> ~Ø170 (one parameter) to clear the balance rim.

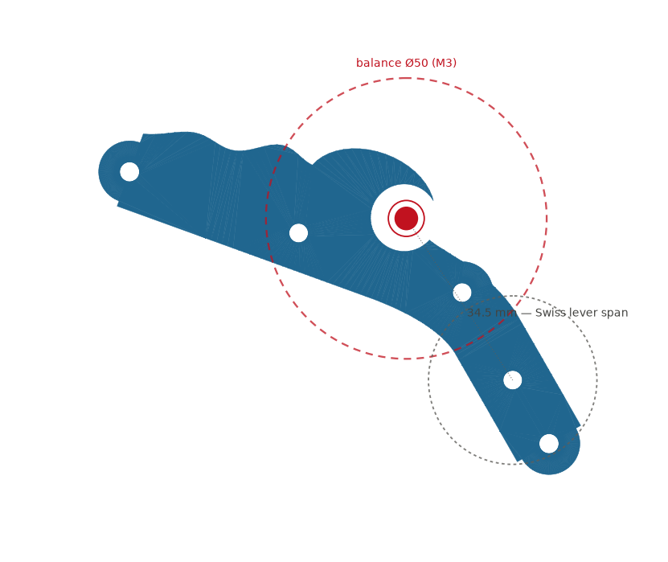
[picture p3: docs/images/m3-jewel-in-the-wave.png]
jewel in the wave


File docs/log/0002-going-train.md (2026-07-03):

# 0002 — Going train design (July 2026)

Designed ahead of Milestone 1 physical validation (deliberate: design
capital now, troubleshoot from measurements later).

## Train math

Constraint chain: 1 Hz balance → 30t escape wheel at 30 s/rev → seconds
arbor at 60 s → drum at 18.75 min/rev so that 3.2 spring turns = 60 min.
Solved with three stages: 72/16 × 50/12 × 24/12. The 60.0000 s seconds
arbor falls out exactly — integer tooth counts, no approximation.

Non-obvious inversion vs. real watches: our barrel turns FASTER than a
watch barrel (18.75 min/rev vs ~7 h/rev) because the printed spring only
yields ~3.2 turns. Minute/hour display will therefore come from a
reduction off the train in M4 (motion works), not from a 1 rev/h center
wheel. Clocks have done this for centuries; it costs two small gears.

## Decisions

- **Cycloidal teeth** (epicycloid addenda / radial-flank pinions, BS978-ish
  simplification proven by the printed-clock canon). Involute undercuts at
  12-leaf counts; cycloidal is also the horological statement.
- **Module 1.0**, backlash 0.15 tangential — chunky, printable, tunable.
- **Layout**: whole train folded into the pillar gap at azimuth 245.7°,
  clearances asserted pairwise in tests (which caught two real collisions
  during design: W4 past the rim, and the bridge band sweeping a pillar).
- **Drum = great wheel**: 72t ring gear cut into the drum's lower band.
- **Printed Ø3 pivots** for rig v1; music-wire upgrade is a parameter.
- **Tripod confession**: M1's pillar generator made 4 positions, 2 identical
  (5.7+180 == 125.7+60). Shipped plates have 3 unique holes. Fixed as an
  intentional 3-pillar design + a distinctness test.

## The wave (decor.py)

Bridge body = Chaikin-smoothed spine through its five bearing points,
offset asymmetrically: plain inboard edge, outboard edge lifted by three
gaussian swells rising to a crest, topped by a logarithmic-spiral curl.
W1 wheel got whirlpool spokes (four 70°-swept arcs).

Geometry lessons paid for this session:
1. OCCT will happily extrude a self-intersecting polygon into a solid with
   an untriangulatable skin — watch for "null triangulation" STL warnings.
   Concave-side polyline offsets fold at corners; smooth the spine first.
2. Polygon winding is load-bearing: a clockwise loop's face normal points
   -z and extrude() follows it. decor normalizes all loops to CCW.

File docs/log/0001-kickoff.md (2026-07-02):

# 0001 — Kickoff decisions (July 2026)

## What this project is

Open-source watch movement engineering, built in public, aiming at two novel
complications: a **haptic metronome** (dedicated barrel, wrist-tap output) and
a **high-accuracy tide indication**. The path: design our own printable,
complication-ready caliber (M1) and learn by printing and testing every stage.

## Decisions and why

**CAD = build123d Python code in git, not GUI CAD.**
Precision watch geometry (cycloidal profiles, escapements, springs) is scripted
even in professional GUI workflows; code-first gives us git diffs, pytest
geometry checks, parametric tolerance iteration, and zero-cost reproducibility
for contributors. Fusion 360's official MCP is paid-tier-only and its cloud
files fight version control. FreeCAD 1.1 is the reviewer/viewer (same OCCT
kernel as build123d → lossless STEP).

**Own caliber instead of printing an existing design.**
No proven running conventional printed watch movement exists (July 2026 —
verified sweep of Printables/MakerWorld/Thingiverse). Laimer's tourbillon
(proven, CC-BY) contributes print know-how — module ≥0.7, PLA gears + PETG
springs, printed spiral springs work, pin bearings — but is architecturally a
dead end for stacking complications. OpenMovement's OM10 (CC BY-SA, STEP
behind free registration) is the architecture textbook: base movement +
bolt-on module philosophy. We copy the concept, not the geometry.

**Scale: Ø110 mm desk movement.** Watch architecture, clock size. Laimer
proved the scale runs; FDM owns it.

**Licenses:** CERN-OHL-S v2 for hardware (also required for compatibility if
we port MrBunsy's CERN-OHL-S escapement/gear code), MIT for tooling.

**Winding convention:** clockwise (viewed from dial side). Mainspring spiral
opens CCW outward; ratchet blocks CCW.

## Milestone 1 scope

Going barrel + test stand (11 printed parts, 5 M3 fasteners). Success =
measurable stored energy: wind, hold on click, release drum via lock pin,
log turns/torque/spin-down. Torque curve feeds Milestone 2 train sizing.

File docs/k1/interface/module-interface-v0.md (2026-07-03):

# Caliber K1 complication-module interface — v0 (draft)

The whole point of K1: complications bolt on without redesigning the base.
This contract is versioned; modules declare which version they target.

## Drive takeoffs (rotating outputs a module may mesh with)

| Takeoff | Period | Where | Status |
|---|---|---|---|
| Seconds | exactly 60 s | W4 arbor | live since M2 |
| Minute | exactly 3600 s | T arbor (M4) | ratios locked, geometry pending |
| Hour | exactly 43,200 s | hour wheel on T (M4) | ratios locked |
| Barrel | 1125 s | drum ring gear, 72t module 1 | live since M2 |

All takeoff gearing is module 1.0 cycloidal per `gears.py`; a module meshes
by placing its input pinion at standard center distance m*(z1+z2)/2.

## Mechanical mounting

- Fastener standard: M3, socket head, with printed hex-nut pockets.
- Module footprint: the free plate sector (azimuth ~0-130 deg, r 44-80)
  plus the airspace above the spider (z > 33 rel plate).
- Height budget: base movement tops out at z 49 (cock arm) over the wave
  only; elsewhere z 33. Modules may build to z 60.
- Every module ships as parametric build123d code + its own clearance
  tests against `train_layout()` / `m3_layout()` — CI rejects collisions.

## Power budget (to be measured on the bench)

Milestone 1's torque test defines available drive torque; a module may
load the minute takeoff by at most 10% of measured drum torque (rule of
thumb until real data lands). The haptic metronome (M6) uses its own
barrel and only takes TIMING from this interface, not power.

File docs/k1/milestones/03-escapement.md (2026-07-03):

# Milestone 3 — Escapement + Balance ("it ticks")

A pin-pallet (Roskopf) lever escapement — chosen over the club-tooth Swiss
lever because cylindrical pins + pointed teeth tolerate FDM error — driving
a Ø50 balance at 1 Hz on a printed PLA hairspring. Predicted period 1.037 s;
trim with M3 nuts in the 6 balance-rim holes (add nuts = slower, ~3%/nut).

The balance jewel — a real 4 mm red glass cabochon, working as a cap jewel —
sits on the balance cock dead over the tube of the breaking wave.

## Parts to print

| Part | Material | Nozzle | Notes |
|---|---|---|---|
| `escape_wheel` | PLA | 0.2 | teeth are the precision feature |
| `pallet_lever` | PETG (regular) | 0.2 | prints on its back, pins up; the flexing... it doesn't flex, but pins take impact |
| `roller`, `balance_staff` | PETG | 0.2/0.4 | staff prints vertical |
| `balance_wheel` | PLA | 0.4 | 100% infill — inertia is the point |
| `hairspring` (+2 spares) | **PLA only** | 0.4 | 0.45mm walls; rate depends on E of PLA; no combing/wipe |
| `tube_chaton` | PLA | 0.4 | glue 4mm cabochon later — it caps the COCK, not this |
| `platform`, `balance_cock` | PLA | 0.4 | cock prints lying on its side |
| `rig_plate` v3, `wave_bridge` v3, `esc_arbor` v2 | PLA/PETG | 0.4 | reprints (Ø170 plate, pallet pad, wheel seat) |

## Hardware added this milestone

- 2× M3×12 + nuts (balance cock foot)
- 1× 4mm red glass cabochon (craft store / Etsy, ~$3) — glued into the
  cock's top pocket; its underside is the balance's upper end-stone
- Optional: 2× Ø2×6mm steel dowel pins to replace printed pallet pins

## Expected bench-tuning (this is v0.1 of a hard mechanism)

1. Escapement lock/drop: tune `Escapement.engage` (1.6) in ±0.2 steps and
   reprint the lever — 15 min print.
2. Beat: rotate the hairspring collet on its D-flat to center the impulse
   pin between the banking posts at rest.
3. Rate: nuts in rim holes; big steps via `Balance.hs_t` (t³ leverage).
4. Overbanking (no guard pin in v0.1): if the fork jumps the roller on
   knocks, print the guard-pin lever variant (planned v0.2).

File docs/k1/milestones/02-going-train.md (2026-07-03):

# Milestone 2 — Going Train

**Goal:** the wound barrel drives a three-stage gear train instead of
free-spinning. Pull the lock pin and the whole train blurs; the W4 arbor —
the future seconds hand — turns at exactly 1 rev/60 s ratio to the drum.
This validates cycloidal gear meshing, printed pivots, depthing, and the
layout that Milestone 3's escapement will regulate.

wave bridge

## The timing chain (all ratios exact)

| Stage | Drives | Ratio | Period |
|---|---|---|---|
| Drum, 72t ring gear | W1 pinion, 16 leaves | 4.5 | drum: 18.75 min/rev |
| W1 wheel, 50t | W4 pinion, 12 leaves | 4.1667 | W1: 250 s |
| W4 wheel, 24t | escape pinion, 12 leaves | 2.0 | **W4: 60.0000 s** |
| — | — | — | escape: 30 s (→ 30t wheel @ 1 Hz in M3) |

3.2 usable spring turns × 18.75 min/rev = **60 min design runtime**.
Teeth are **cycloidal** (epicycloid wheel addenda, radial-flank pinions) —
the horologically correct form for low-count pinions, generated in
[gears.py](../../caliber_k1/gears.py).

## The ocean, in the frame

- The **train bridge is a breaking wave**: three swells build along its
  outboard edge to a crest that curls over in a logarithmic spiral. It
  carries all three upper pivots and seats on two integral posts.
- The **W1 wheel's spokes are a whirlpool** — four arcs sweeping 70° from
  hub to rim. Both live in [decor.py](../../caliber_k1/decor.py) and will
  carry through the rest of the caliber.

## Parts to print

| Part | Material | Nozzle | Layer | Infill | Notes |
|---|---|---|---|---|---|
| `rig_plate` | PLA | 0.4 | 0.20 | 25% | Ø150. Replaces M1 bottom_plate. Posts print up. |
| `drum` (reprint) | PLA | 0.4 | 0.20 | 25% | Now carries the 72t ring gear. Everything else in the barrel is unchanged. |
| `wave_bridge` | PLA | 0.4 | 0.16 | 40% | Flat; the star of the show — print it clean. |
| `w1_arbor` | **regular PETG** | 0.4 | 0.12 | 100% | Vertical, pivot down, with a brim. Wheel is a large overhang — see below. |
| `w4_arbor` | **regular PETG** | 0.4 | 0.12 | 100% | Vertical + brim. |
| `esc_arbor` | **regular PETG** | 0.4 | 0.12 | 100% | Vertical + brim. |

**Arbor overhang note:** wheels sit partway up their arbors, so each wheel's
underside is a large flat overhang. Print arbors with **supports enabled
(snug, from build plate only)** and peel them from the wheel underside — or
slice with a 0.2 nozzle at 0.10 for crisper teeth if patience allows.
Expect to ream the plate/bridge bushings (3.4 mm → 3.5 mm drill twisted by
hand) and polish the printed pivots with fine sandpaper.

**Hardware: none new.** Same 3× M3×40 stand bolts. (Milestone 1's plates
had only three unique pillar positions — a v1 bug now embraced as a tripod;
the fourth printed pillar is a spare.)

## The test (film this)

1. Assemble: rig plate → train arbors into their bushings → barrel cartridge
   between plates as in M1 → wave bridge onto its posts over the train.
2. Check free running BEFORE the spring: every arbor should spin from a
   breath of air. If not, find the tight pivot and ream/polish.
3. Wind 1 turn with the lock pin in. Pull the pin.
4. **Count:** mark the W4 arbor; the drum should make exactly 3 revolutions
   while W4 makes 56.25 (i.e., in ratio 18.75:1). Any slip/skip = mesh problem.
5. Time the spin-down from a full 3-turn wind. Unregulated, it will run down
   in seconds — that's expected. The number feeds M3's escapement design:
   60 min runtime ÷ spin-down seconds ≈ the braking factor the escapement
   must provide.

## Tuning knobs

- Teeth bind / feel gritty → raise `Train.backlash` (0.15 → 0.20) and reprint
  the smaller part of the offending pair.
- Teeth skip under load → deepen mesh: lower backlash, or check arbor bushings
  for slop (`pivot_clearance`).
- Arbors rattle → drop `Train.pivot_d` clearance in `Tolerances`.
- Wave not dramatic enough on camera → `decor.wave_bridge_face` exposes
  `half_w`, `crest_at`, `curl_r`, and the swell table. Iterate freely; the
  bridge is a 20-minute print.

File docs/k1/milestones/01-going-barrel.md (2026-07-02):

# Milestone 1 — Going Barrel

**Goal:** a wound mainspring that stores real energy and releases it on command.
Wind the arbor with the key (the click holds it), pull the drum-lock pin, and
the drum spins down — pointer whirling — until the spring is slack. This
validates: printed spiral springs, printed pivots and journals, ratchet-and-click
geometry, and our print tolerances. Everything downstream (the going train)
hangs off this barrel.

## Parts to print

| Part | Qty | Material | Nozzle | Layer | Infill | Notes |
|---|---|---|---|---|---|---|
| `mainspring` | 1 (+spares) | **regular PETG — not HF** | 0.4 | 0.20 | 100% | The consumable. Print 2–3; creep kills them over days. No supports; print flat. |
| `drum` | 1 | PLA | 0.4 | 0.20 | 25% | Flat on floor. |
| `cover` | 1 | PLA | 0.4 | 0.20 | 25% | Tabs up (print upside-down). |
| `arbor` | 1 | PETG (HF is fine) | 0.4 | 0.12 | 100% | Vertical, square up. Torque part. |
| `ratchet_wheel` | 1 | PETG (HF is fine) | 0.4 | 0.16 | 60% | Flat. |
| `click` | 1 | **regular PETG — not HF** | 0.4 | 0.16 | 100% | Flexure — PLA will creep, PETG HF may snap. Pegs up (print upside-down, or supports under pegs). |
| `winding_key` | 1 | PETG (HF is fine) | 0.4 | 0.20 | 40% | Socket down, no supports needed up to the handle. |
| `lock_pin` | 1 | PETG (HF is fine) | 0.4 | 0.16 | 100% | Head up. |

**Why "not HF" on the spring parts:** high-flow PETG (e.g. Bambu PETG HF) trades
mechanical margin for print speed — by Bambu's own datasheet it yields at
~34 MPa vs ~47–50 MPa for regular PETG, and breaks at 8.6% elongation where
regular PETG bends without fracturing. A wound spring and a flexing pawl are
exactly the parts that need that ductility headroom; a stressed HF spring takes
a set (loses torque) sooner and fails by sudden snap. HF's stiffness is fine —
use it freely for arbors, wheels, keys, and structure. Whatever PETG you print
springs from: dry it first (65 °C, 4+ h) — wet PETG loses layer adhesion badly.
| `bottom_plate`, `top_plate` | 1 ea | PLA | 0.4 | 0.20 | 25% | Flat. |
| `pillar` | 4 | PLA | 0.4 | 0.20 | 40% | Vertical. |

H2C dual-nozzle note: PLA and PETG parts can share a plate with one material
per nozzle. Keep the 0.2 mm hotend in reserve — Milestone 3 (escapement) will
want it; nothing here needs it.

## Hardware BOM (the entire metal shopping list)

| Item | Qty | Source |
|---|---|---|
| M3 × 40 socket-head cap screw | 4 | any M3 assortment kit / McMaster 91290A130 |
| M3 × 8 socket-head cap screw | 1 | (click mount) |
| M3 hex nut | 5 | |

That's it — by design. Milestone 2 adds steel pins for train arbors.

## Assembly

1. Ream the plate bushings (Ø8.4) and drum/cover bores (Ø10.4) with a drill
   bit spun by hand until the arbor turns freely. This step is 80% of success.
2. Spring into drum: outer tab through the wall slot, D-ring over the arbor
   hub (flat to flat), coils sitting free of floor and walls.
3. Cover on, tabs into the drum rim notches.
4. Barrel cartridge between the plates; bolt the stand together (M3×40).
5. Ratchet wheel onto the winding square; click over its pegs, M3 + nut snug.
6. Key on. **Wind clockwise.** The click should snick past each tooth.

## The test (film this)

1. Lock-pin in (through top plate into cover): drum can't turn.
2. Wind 3 full key-turns clockwise. Click holds the arbor between strokes.
3. Pull the pin. Drum spins down — count pointer revolutions and time it.
4. Torque measurement: wrap thread around the drum rim, hang a small weight
   (start ~100 g), wind one turn, and find the weight the spring just lifts.
   Torque ≈ weight × 0.036 m. Log wound-turns vs. torque — that curve sizes
   the going train in Milestone 2.

## Tuning knobs (expect to iterate)

- Spring too weak / too strong → `Mainspring.thickness` (1.6) or `.height` (16).
- Arbor binds → `Tolerances.pivot_clearance` (0.20) up by 0.05.
- Click skips under load → thicken `click_arm_t` / deepen tooth engagement.
- Spring coils fuse while printing → raise coil count spacing: fewer `coils`.

Every change is one line in `parameters.py`; re-run the export, reprint only
the affected part.

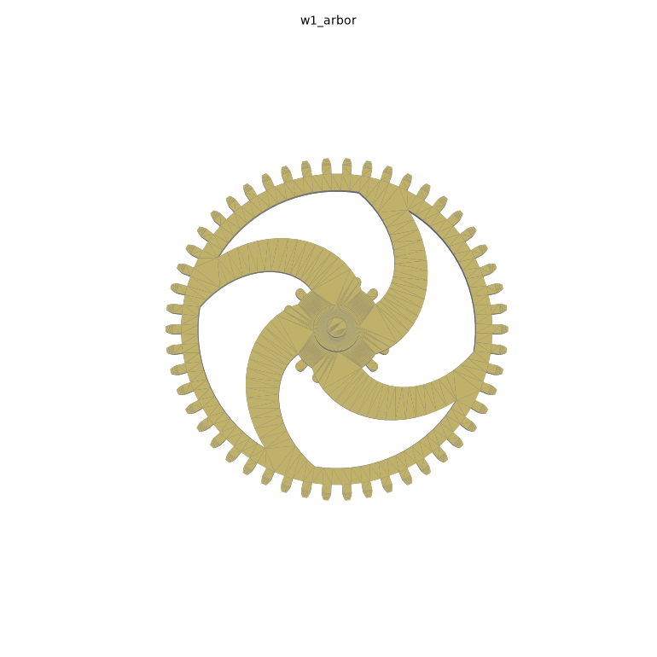
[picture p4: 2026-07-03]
docs/images/m2-w1-wheel.png

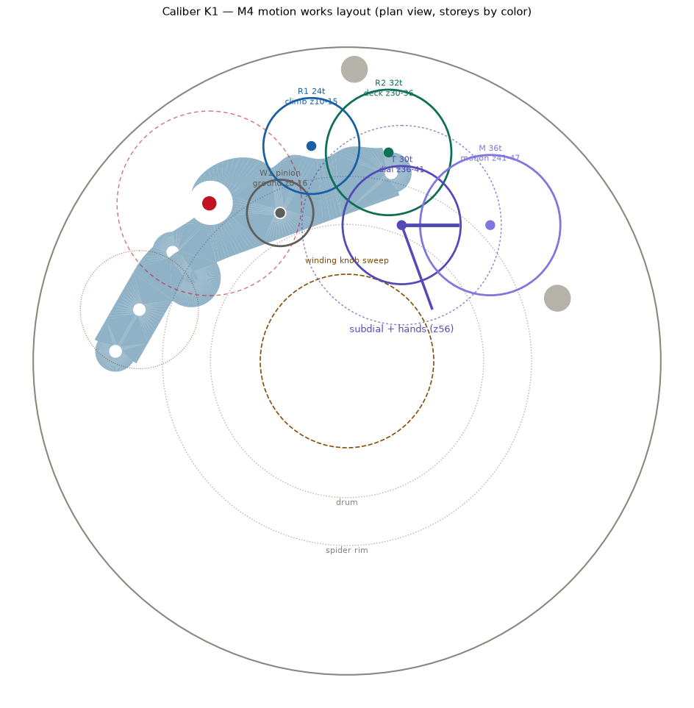
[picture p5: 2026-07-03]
docs/images/m4-layout-plan.png

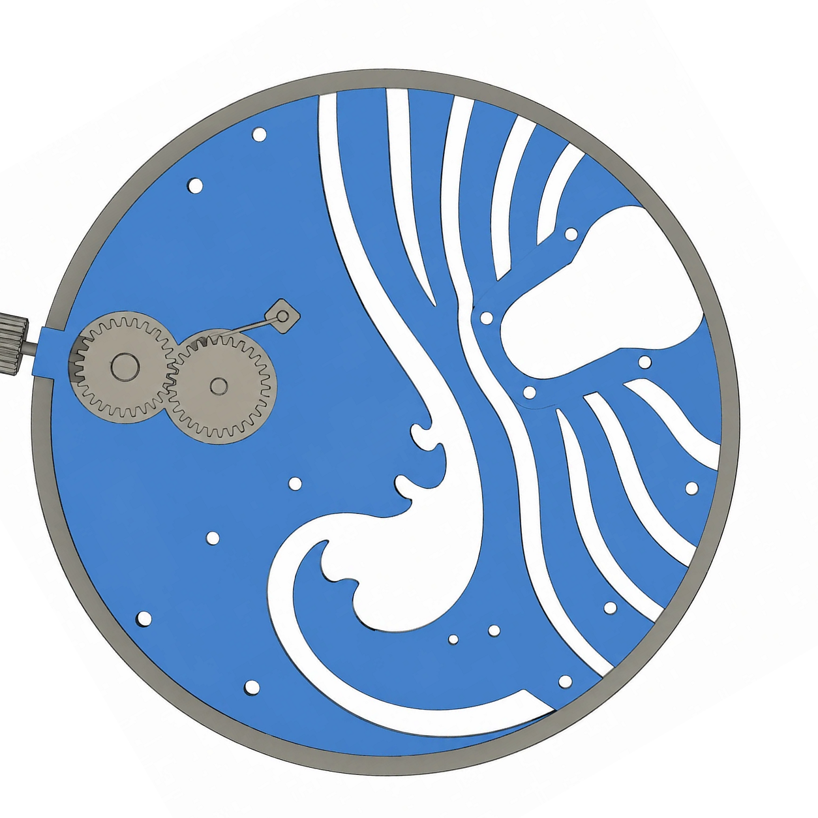
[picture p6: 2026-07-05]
art/wave_reference_9oclock.png

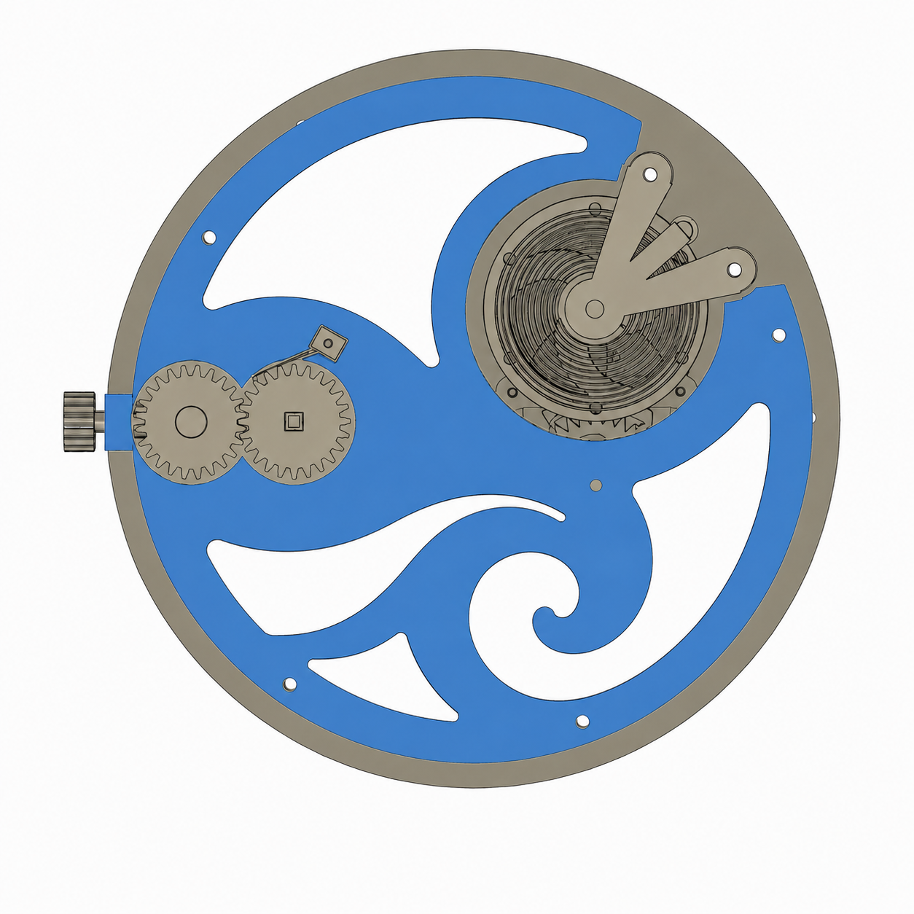
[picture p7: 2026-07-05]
art/wave_reference.png

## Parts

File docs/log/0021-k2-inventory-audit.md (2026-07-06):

# 0021 — K2 inventory audit: the massing was missing 18 parts

**Date:** 2026-07-05 · **Trigger:** Jon — "are you certain you identified
all the parts and skeletal pieces before you ran your massing?"

Honest answer: no. K1 has an explicit `INVENTORY` + a test that fails if
the massing forgets a part. K2 never got that discipline; massing r5
placed the major rotating masses and the winding line but nothing forced
a full recital first.

## The audit (`test_k2_inventory_complete`)

20 of ~38 parts were in the r5 model. The 18 missing, by whether they
move the massing:

**Change the plate (should have been in the massing):**
- the two-position clutch works — `m_clutch`, `m_setting_lever`,
  `m_detent`, `m_clutch_spring` (the whole novel keyless mechanism; only
  its crown wheels were present)
- the metronome balance cock `m_cock` + its feet
- the metronome train bridge + pillars `m_bridge`/`m_pillar`
- the barrel click `m_click`; the impulse roller `m_roller`

**Live inside a placed part (parts-stage, now listed):** mainspring +
drum cover (in the drum), balance staff, banking pins + pallet strap,
hammer return spring + pivot, pusher spring + pen-stop, train cock.

## What adding them proved

The clock core and every rotating metronome mass stay clean on O250.
But the metronome's own **bridge pillars have nowhere to stand** — the
r5 solve minimized plate radius and packed the met train with no reserved
pillar sites, so hand-placed pillars land on its own wheels. The keyless
clutch train also needs real spacing along the stem. Both belong in the
`m_click`/`m_roller`/`m_cock` were absorbed fine; the structural skeleton
was not. `test_k2_full_cast_debt` proves the masses are clean and pins the
remaining conflicts to exactly {pillars, clutch train}.

## Consequence

**O250 is provisional.** K2 needs a full-cast RE-SOLVE that reserves
pillar sites for the metronome bridge and spaces the keyless clutch train
— and the plate will grow. K1's inventory-first discipline is now
mirrored in K2 so this can't recur silently.

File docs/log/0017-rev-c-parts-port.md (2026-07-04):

# 0017 — Rev C parts port: the movement gets real on the approved massing

**Date:** 2026-07-03 · **Status:** movement_r1.step exported, 73 tests green,
adversarial verification pass run before Jon's gate

Jon approved massing r3 ("This is it!"), which authorized part modeling on
`REVC_LAYOUT`. Everything proven in rev B was re-derived — not copied — onto
the rev C coordinates and z-map (`caliber_k1/revc_parts.py`).

## Three architecture facts the port surfaced

Working the z-map to part level exposed consequences the massing implied but
never spelled out:

1. **The barrel is a hanging barrel.** The 80t minute wheel at plane B
   overhangs the barrel center by 6mm (center distance 35 < wheel radius 41),
   so the barrel arbor tops out at z11 — no upper bearing, no ratchet above
   the bridge. Single plate-side journal (boss + recess floor), exactly like
   modern wristwatch practice. Winding therefore enters from the **dial
   side**: the arbor ends in a 4×4 square below the plate. The keyless stage
   builds on that square; until then it key-winds like M1.

2. **The pallet cock became the bay strap.** With the ring at z7.6 there is
   no headroom for rev B's U-cassette. The removable pallet bearing is now a
   thin strap (z6.45–7.0) spanning the recessed bay, feet screwed M2 to the
   plate *under the ring's airspace* — remove two screws, lift the fork.
   Serviceability contract preserved; banking pins moved to the bay floor
   (integral plate posts).

3. **Mesh exactness beats grid rounding.** The solver's 0.1mm coordinate
   rounding left fourth–escape 0.08 tight; escape snapped to (24.4, −40.6)
   for exact 27.0 (and escape–balance stays exactly 40.0). A permanent test
   bounds every mesh's center-distance error to (−0.02, +0.06).

## What's in movement_r1 (17 components)

Mainplate (bay recess + cups + banking pins + bushings + every screw seat),
hanging barrel (drum with integral 56t band, arbor, cover), four train
arbors (minute has the **through-bore + dial-side D-stub** — the indirect
minute interface), 30t club escape wheel, Swiss lever (variant lock/draw),
bay strap, two-tier roller, Ø3-rod balance staff, Ø52 balance, slit-collet
hairspring, balance cock (coplanar with the bridge, cabochon pocket, stud
post), and the plain broad bridge (r79, four rim pillars, cock nestled in
its dilated-silhouette cutout — the NH35 composition; the wave is sculpted
last, per 0011).

## The adversarial review earned its keep

69 agents (six lenses: kinematics, z-stack, watchmaker, test rigor,
variant switch, DFM; every finding re-verified by a skeptic) reviewed the
port BEFORE Jon saw it: 61 confirmed findings collapsing to ~20 unique
defects. The first draft's escapement was dead on arrival THREE ways —
banking pins pinched the fork (zero swing), the fork's guard-level floor
rammed the safety roller at every angle, and the impulse pin bottomed in
the notch. Also: hairspring severed in two by the collet slit, the cock's
stud post floating in air, the builder mis-phasing three meshes in the
exported STEP, and the roller carrying its pin on a bar that swept the
horn zone (real rollers are a table with the pin proud at the rim; real
horns are SHORT — anatomy corrected). All fixed; the suite gained the
gates that were structurally blind to these:

- assembled-pose interference gate over the exported movement (meshes
  phase-CHAINED via za*ta + zb*tb = const, plus 12 disjointness pairs)
- lever-vs-plate and lever-vs-roller probes over REACHABLE states only
  (draw holds the away-bank after pin exit — coupled states excluded)
- click settle/bite profile over one tooth pitch
- both-ends z-band + single-solid check for all 19 parts

New parts the review forced in: dial-side 24t ratchet + M1's flexure
click (the hanging barrel now holds wind AND is axially retained), the
bay-strap became a through-bearing (no unprintable 0.15 ceiling), and
`Variant` gained `backlash`/`press_r` fields so metal reflows the mesh
and the press fits.

## Gates

`test_revc_parts.py` (9 gates) + the standing global `check_all` gate;
75 tests green on print; metal runs 8/9 with the escapement drop-window
retune explicitly skipped-and-tracked (the 1.5/13 deg table angles from
log 0015 leave no drop with 0.12 backlash — the DFM pass must retune
lock/draw/backlash together).

## Honest flags

- Drum interior shrank with the flat stack: ~2.4 usable turns × 4h/rev ≈
  **10h runtime** (not the 18 the massing note estimated). Bench validates;
  strip 2.2×6.0 recovers rev B torque via t³.
- Keyless works, dial-side motion works (1:1 transfer + cannon), moon train:
  next stages. Dial-side pockets must avoid the bay recess plan-area
  (constraint recorded in `revc.py`).

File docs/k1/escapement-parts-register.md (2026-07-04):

# Escapement & balance parts register (after ciechanow.ski/mechanical-watch)

Jon's reference: Bartosz Ciechanowski's "Mechanical Watch". Full analysis
in the research transcript; this register maps every part to K1 status
and variant assignment. Print scale is ~5x: lock depth ~1.2mm vs FDM
error +-0.15 — THE reason 5x works where 1x FDM cannot.

| Part | K1 status | print variant | metal variant |
|---|---|---|---|
| Escape wheel (club) | BUILT, probed | printed | steel, watch angles |
| Pallet fork body | BUILT, probed | printed | steel |
| Pallet stones | BUILT (integral faces) | integral, polished; upgrade: slotted acetal stones = adjustable lock | ruby/insert pockets (DFM) |
| Guard element | BUILT (floor finger) | printed; upgrade: pressed wire pin (bendable tuning) | steel dart |
| Fork horns + slot | BUILT (two-level) | printed | steel |
| Banking | BUILT (bridge pins) — essay's movement banks on bridge knobs too | printed pins; upgrade: M3 brass grub screws = master adjustment | eccentric pins |
| Pallet bridge | BUILT (removable, 2x M3) | printed | milled |
| Impulse pin | BUILT (printed, on roller) | UPGRADE: steel/brass dowel, one flat filed (the D matters) | jewel |
| Two-tier roller + crescent | BUILT | printed one-piece (essay's double roller) | steel |
| Balance staff | BUILT printed — TO CHANGE | **steel rod (non-negotiable — amplitude lives on pivot friction)** | turned steel |
| Balance bearings / end stones | printed bushings — TO CHANGE | brass/PTFE bushings or MR52 + polished shim thrust | hole jewels + cap jewels |
| Shock protection | absent | omit (steel staff at desk scale doesn't need it); great content later | Incabloc-style (DFM) |
| Hairspring | BUILT printed PLA | printed (Laimer precedent; creep = recalibration story) | Nivarox-class, sourced |
| Collet | BUILT solid — TO CHANGE | slit it: friction-rotatable = BEAT ADJUSTMENT (audible in a metronome!) | split steel |
| Stud / regulator / curb pins | absent | printed arm + wire curb pins + eccentric-screw fine adjust (essay's design) | conventional |

## System notes adopted
- Train torque starvation is a FEATURE (anti-rebanking) — size the spring
  to minimum healthy amplitude.
- 5x printed balance lands 0.5-2 Hz naturally — metronome territory;
  a gift for the M6 haptic complication.
- Print-variant metal shortlist (the honest BOM): steel staff rod,
  impulse dowel pin, guard/curb wire, balance bushings + thrust shims.

Queued geometry changes: steel-staff adapter hubs, slit collet,
regulator assembly, grub-screw banking bosses.

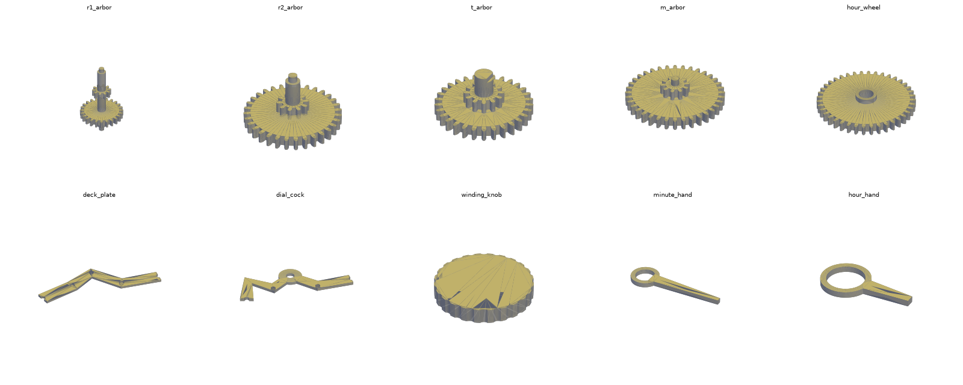
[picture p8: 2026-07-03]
docs/images/m4-parts.png

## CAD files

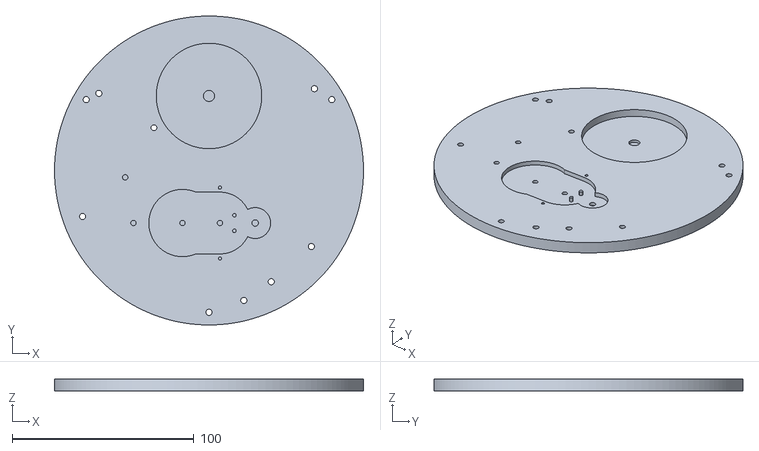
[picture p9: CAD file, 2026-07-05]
exports/k1/print/mainplate.stl
170.0 x 169.9 x 6.50

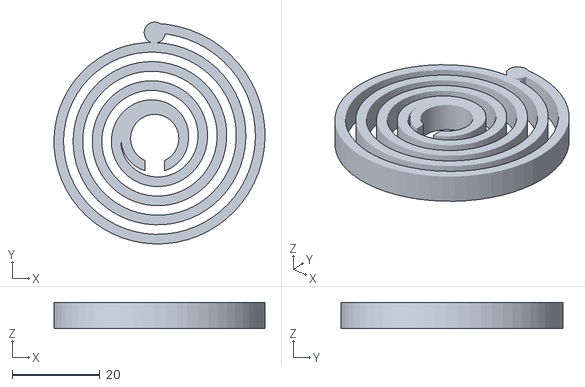
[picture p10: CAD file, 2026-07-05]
exports/k1/print/mainspring.stl
48.2 x 50.7 x 6.00

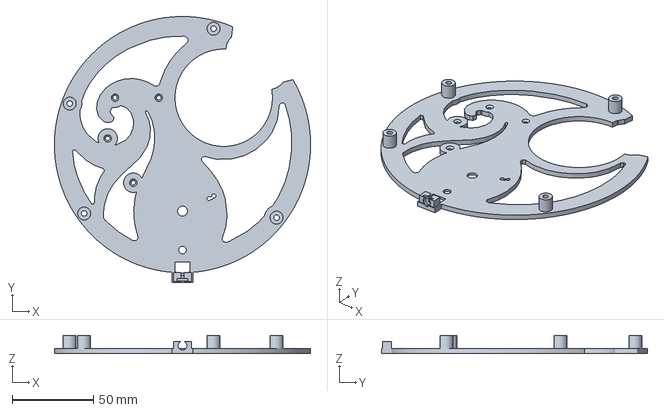
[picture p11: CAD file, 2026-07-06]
exports/k1/print/barrel+winding-group-k1.3mf
158.0 x 164.0 x 11.2 mm

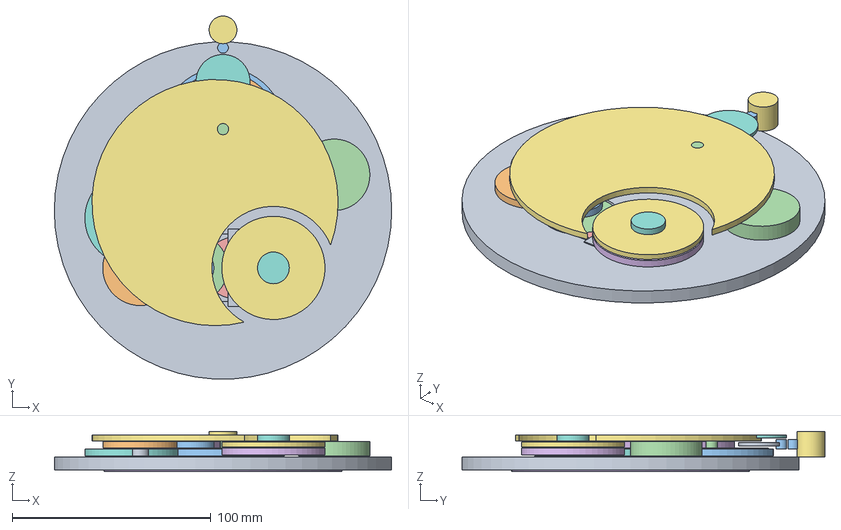
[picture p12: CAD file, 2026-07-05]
exports/k1/revc/massing_r6.step
170.0 x 182.9 x 20.3 mm
mainplate (recesses shown)
drum
drum_gear
b_arbor
min_p
min_w
third_p
third_w
fourth_p
fourth_w
esc_p
esc_w
roller
ring
spring
ratchet
crown_w
crown_w (2)
click_zone
stem
stem (2)
module_bay
lever_hub
lever_fork
bridge (cover zone)
balance cock (arm zone)
pallet strap
dial works: hour
dial works: cannon
dial works: moon_p
dial works: xfer_c
dial works: xfer_a
dial works: w1_w
dial works: w1_p
dial works: w2_w
dial works: w2_p
dial works: disc
dial works: motion_w
dial works: motion_p
dial works: i1
dial works: i2
dial platform
crown (outside the rim, mid-height)

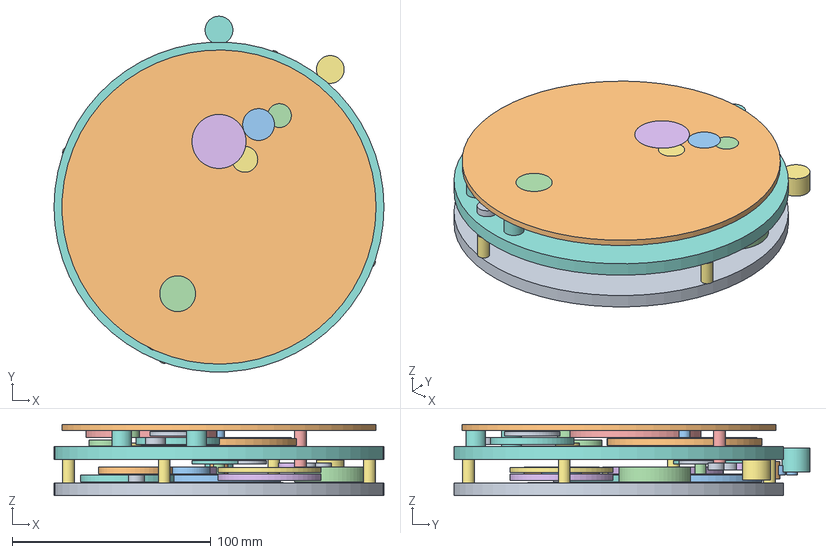
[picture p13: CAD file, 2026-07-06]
exports/k2/two_sided_r2.step
166.0 x 178.9 x 35.9 mm
base plate
base: drum
base: drum_gear
base: b_arbor
base: min_p
base: min_w
base: third_p
base: third_w
base: fourth_p
base: fourth_w
base: esc_p
base: esc_w
base: roller
base: ring
base: spring
base: ratchet
base: crown_w
base: click_zone
base: stem x 3
base: module_bay
base: lever_hub
base: lever_fork
module standoff x 4
module plate
mod: m_drum
mod: m_drum_gear
mod: m_arbor
mod: m_p1
mod: m_w1
mod: m_p2
mod: m_esc_w
mod: m_cam
mod: m_ring
mod: m_spring
mod: m_lever_hub
mod: m_lever_fork
mod: m_hammer
mod: m_roller
mod: m_ratchet
mod: m_click
mod: m_cock
mod: m_pillar x 2
mod: m_knob_line
module bridge (cover zone)
winding corridor (reserved) x 7
crown (one, two positions)

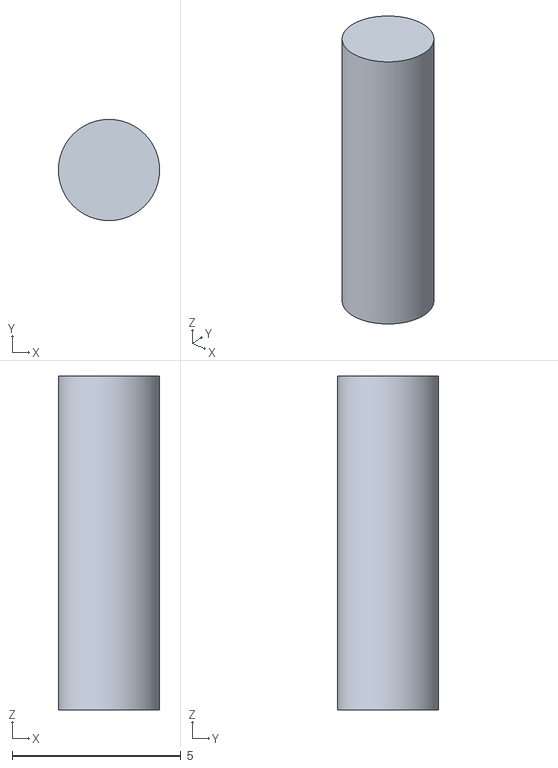
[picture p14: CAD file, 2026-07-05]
exports/k1/print/center_post.stl
3.00 x 3.00 x 9.90

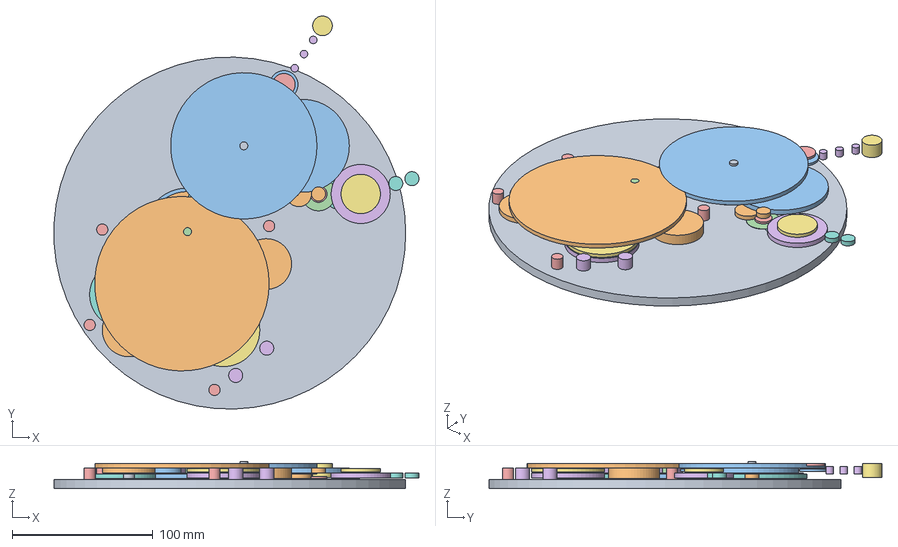
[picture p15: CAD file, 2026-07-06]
exports/k2/massing_r5.step
259.4 x 279.3 x 19.3 mm
K2 plate (ROUND, O250)
drum
drum_gear
b_arbor
min_p
min_w
third_p
third_w
fourth_p
fourth_w
esc_p
esc_w
roller
ring
spring
ratchet
click_zone
module_bay
lever_hub
lever_fork
pillar
pillar (2)
pillar (3)
pillar (4)
cock_foot
cock_foot (2)
m_drum
m_drum_gear
m_arbor
m_p1
m_w1
m_p2
m_esc_w
m_cam
m_ring
m_spring
m_lever_hub
m_lever_fork
m_hammer
m_ratchet
cw1_core
cw1_core (2)
cw2_core
wind_idler
cw2_core (2)
m_stem
m_stem (2)
m_stem (3)
k2_crown
m_knob_line
m_knob_line (2)
m_pusher
clock bridge zone
metronome bridge zone

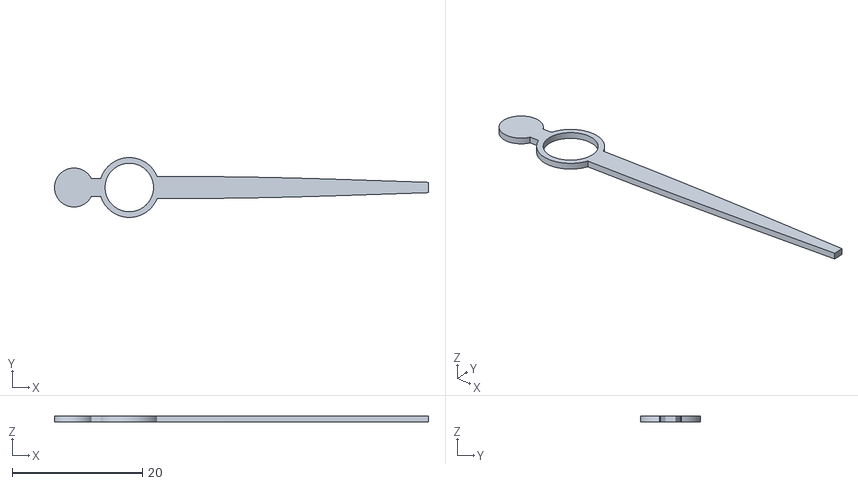
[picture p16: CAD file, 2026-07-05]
exports/k1/print/hour_hand.stl
57.5 x 9.20 x 0.9

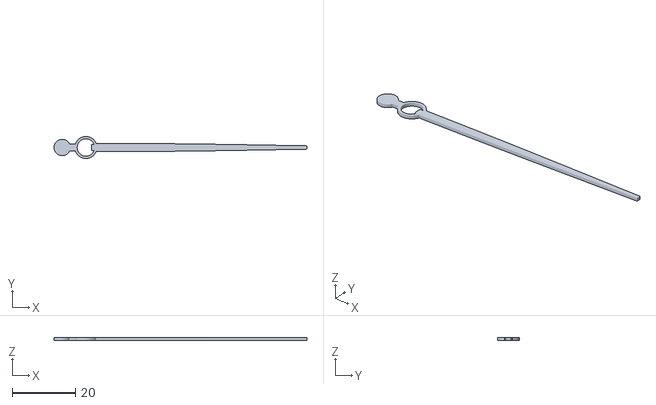
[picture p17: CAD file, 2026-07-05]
exports/k1/print/minute_hand.stl
80.1 x 7.00 x 0.9

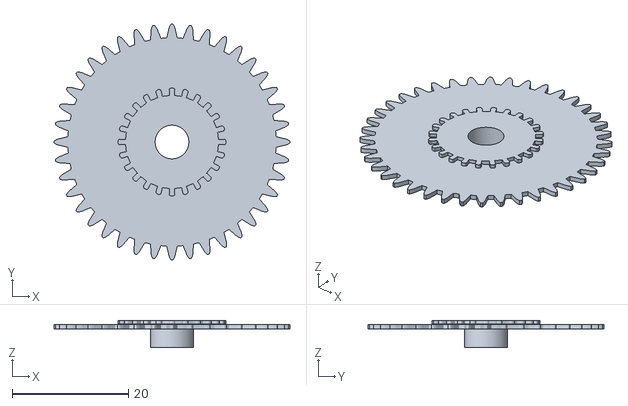
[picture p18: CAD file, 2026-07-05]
exports/k1/print/hour_wheel.stl
40.6 x 40.6 x 4.65

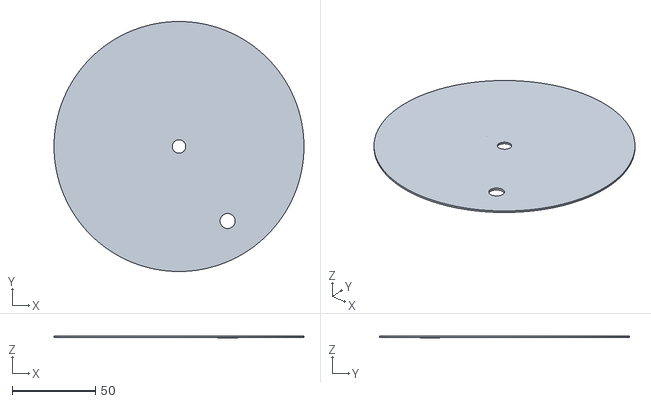
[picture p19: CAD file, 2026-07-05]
exports/k1/print/dial_sheet.stl
150.0 x 150.0 x 1.30

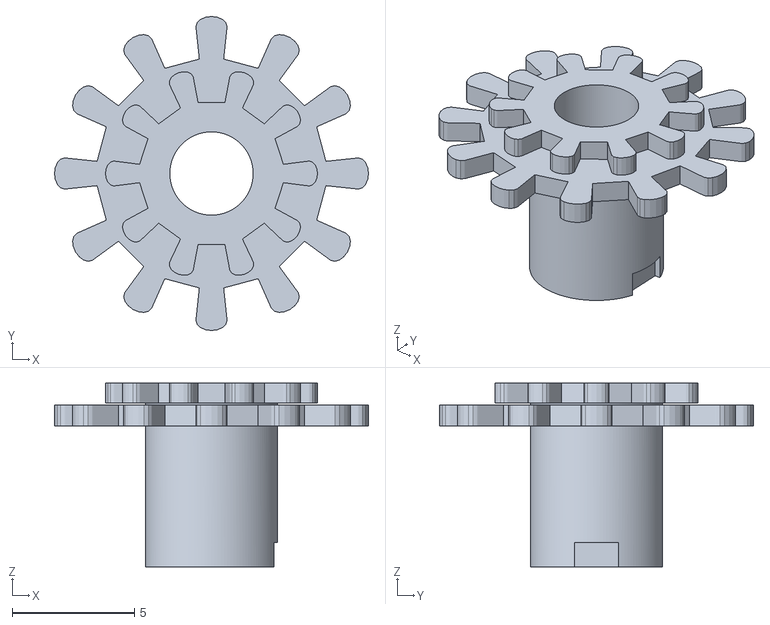
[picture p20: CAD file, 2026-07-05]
exports/k1/print/cannon.stl
12.8 x 12.8 x 7.50

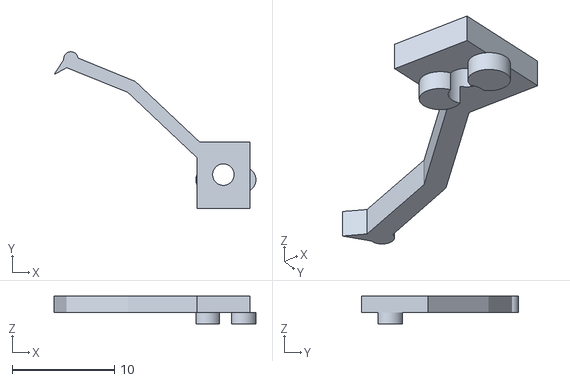
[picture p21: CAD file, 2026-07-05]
exports/k1/print/click.stl
19.8 x 15.3 x 2.70

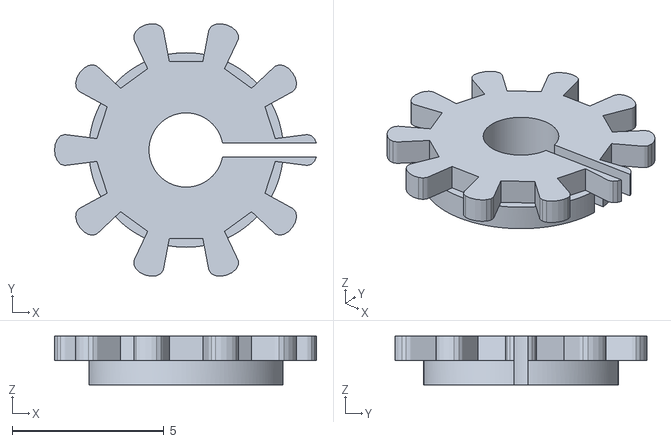
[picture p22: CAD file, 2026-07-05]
exports/k1/print/transfer_pinion.stl
8.62 x 8.31 x 1.60

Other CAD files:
exports/k1/print/bridge_wave.stl
exports/k1/print/pallet_fork.stl
exports/k1/print/fourth_arbor.stl
exports/k1/print/arbor_post_disc.stl
exports/k1/print/arbor_post_i1.stl
exports/k1/print/arbor_post_i2.stl
exports/k1/print/arbor_post_motion.stl
exports/k1/print/arbor_post_w1.stl
exports/k1/print/arbor_post_w2.stl
exports/k1/print/balance_cock.stl
exports/k1/print/balance_staff.stl
exports/k1/print/balance_wheel.stl
exports/k1/print/barrel_arbor.stl
exports/k1/print/bay_strap.stl
exports/k1/print/crown_stud.stl
exports/k1/print/crown_wheel.stl
exports/k1/print/dial_platform.stl
exports/k1/print/drum.stl
exports/k1/print/drum_cover.stl
exports/k1/print/escape_arbor.stl
exports/k1/print/escape_wheel.stl
exports/k1/print/hairspring.stl
exports/k1/print/minute_arbor.stl
exports/k1/print/moon_disc.stl
exports/k1/print/moon_w1.stl
exports/k1/print/moon_w2.stl
exports/k1/print/motion_arbor.stl
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

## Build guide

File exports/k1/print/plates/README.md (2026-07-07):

# Curated slicer plates (Bambu Studio .3mf)

Pre-arranged, support-painted Bambu Studio project files for the K1 print
kit — orientation, painted supports and profile settings already applied
per the [MANIFEST](../MANIFEST.md) and the
[printing guide](../../../../docs/k1/printing-guide.md).

**Curation rule: a plate lands here only after it has produced a clean
print on a real machine.** Scratch slicer projects stay untracked
(gitignored) until they earn it. Name plates `k1-<part-group>.3mf`,
e.g. `k1-arbors-escapement.3mf`, `k1-barrel-winding.3mf`.

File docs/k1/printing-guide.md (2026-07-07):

# Caliber K1 — FDM printing guide (Bambu Studio, H2C)

Settings for printing rev C parts from `exports/k1/print/`. These are watch
parts: module 0.6–1.0 gears with sub-millimeter teeth and press-fit bores,
so dimensional accuracy matters more than speed. Read the calibration note
before the first real run.

## H2C quick-set (Bambu Studio)

**Nozzle: 0.4 mm — install/confirm this and keep it for the whole build.**
The smallest teeth in the movement are the module-0.6 moon-train gears
(~0.9 mm thick at the pitch line), which a 0.4 nozzle renders as ~2 clean
perimeters — proven at this scale. A 0.2 nozzle would sharpen those flanks
but roughly doubles print time and makes every part more fragile; not worth
it for a functional first build. A **standard steel** nozzle is fine —
hardened is only for abrasive (carbon/glass-filled) filament, which we
don't use. *(Later, if you want jewelry-grade dial gears, re-printing only
the moon train with a 0.2 nozzle is the upgrade — recalibrate first.)*

**Machine / plate**

| field | value |
|---|---|
| Nozzle | **0.4 mm**, standard steel |
| Build plate | **Textured PEI** — safe for both PLA and PETG (smooth PEI grips PETG hard enough to chip) |
| Flow dynamics / pressure advance | Auto-calibrate **ON** (leave Bambu's) |
| Auto bed leveling | **ON** every print — matters for the Ø170 flat parts |

**PLA** — start from the **Bambu PLA Basic** profile, then:

| field | value |
|---|---|
| Nozzle temp | 220 °C first layer / 215 °C rest |
| Bed temp | 55 °C |
| Layer height | 0.20 mm plates · 0.12 mm gears |
| Walls / top / bottom | 4 / 4 / 4 |
| Infill | 20% gyroid (plates) · 100% (gears & small parts) |
| Outer-wall speed | 50 mm/s (slow flanks = clean teeth) |
| Brim | 5 mm on the Ø170 parts |
| Supports | Organic (tree), pockets/overhangs only |

**PETG** — select the **Bambu PETG HF** profile (matches your spool) and
**leave its temps and fan as tuned by Bambu**; only change:

| field | value |
|---|---|
| Layer height | 0.12 mm |
| Walls | 4 (hairspring/mainspring are intentionally thin — see Class C) |
| Plate | Textured PEI + a glue-stick release layer |

**Before the real parts:** run Bambu Studio's built-in **flow-rate and
pressure-advance calibration** once per filament (~10 min). It's what saves
you the hairspring and gear reprints.

> Confirm the exact profile *names* and any H2C-specific fields (dual-nozzle
> / AMS options) in your own Bambu Studio — the H2C is new enough that I'd
> rather you verify the machine profile than take my word for a menu label.
> The **values** above are the targets regardless of what the profile is called.

## The one thing that will bite you: clearances are already baked in

The geometry already includes running clearance (0.20 mm on every print
pivot) and gear backlash (0.30 × module). **Do not add more.** In
particular:

- **X-Y hole/contour compensation:** leave Bambu's default *as-is* for the
  first print, then measure and calibrate. Do **not** stack your own hole
  expansion on top of the designed clearance — the bores will come out
  loose and the gears will have lash.
- Your printer's real dimensional offset is unknown until you measure. That
  is the entire point of printing the mainplate first: it is the reference.

**First-print calibration loop:** print the mainplate → with calipers,
measure against these designed values (they already include running
clearance):

- a train pivot bushing (third/fourth positions): **Ø3.0**
- the central minute through-bore: **Ø3.2**
- the barrel recess: **Ø58.0**
- plate thickness: **6.5**

FDM typically comes out with holes *slightly under* nominal (elephant-foot
and over-extrusion pull them in). If yours are consistently ~0.1–0.2 mm
small, add that as X-Y hole compensation and record it in your build log.
Only then print mating parts.

## Global settings (all parts, PLA)

| setting | value | why |
|---|---|---|
| Nozzle | 0.4 mm | 0.2 would be finer for teeth but far slower; 0.4 proven at this module |
| Layer height | **0.12 mm** gears/arbors, **0.20 mm** plate/bridge | teeth need the resolution; the big flat parts don't |
| Walls (perimeters) | **4** | small parts become nearly solid; teeth print as walls, not infill |
| Top/bottom layers | 4 / 4 | seals faces on the flat parts |
| Infill | **100%** small parts, **20% gyroid** plate & bridge | gears must be solid; the plate is stiff enough at 20% |
| Nozzle temp | 210 °C (first layer 220) | standard PLA |
| Bed temp | 55 °C | Bambu textured PEI |
| Print speed | **50 mm/s** outer walls, default elsewhere | slow outer walls = clean teeth |
| Seam | Aligned, tucked to a bore or spoke | keeps the seam off tooth flanks |

## Per-part-class profiles

**Class A — big flat plates** (`mainplate`, `bridge_DRAFT`, `dial_platform`)
- 0.20 mm layers, 20% gyroid, **brim 5 mm** (warp control on the Ø170 disc).
- Mainplate: **dial face DOWN**, tree/organic supports **in the dial
  pockets only** (not under the whole part). Bridge: **top face DOWN**.
- First layer slow (`≤ 30 mm/s`) and a clean bed — adhesion is everything
  on a part this wide.

**Class B — gears, arbors, wheels** (train arbors, escape wheel, crown
wheel, ratchet, motion/moon wheels, roller, balance wheel)
- **0.12 mm layers, 4 walls, 100% infill, 50 mm/s outer walls.**
- Arbors print **vertical** (small pivot up), **brim on** — they're tall and
  thin. Flat wheels print flat.
- **Arbors need painted supports** — each one is a stack of discs on a thin
  stem, and every disc underside is a horizontal overhang (confirmed the hard
  way: unsupported, the wheels spaghetti). Use Tree (manual) and paint ONLY
  under discs with clear air to the plate:
  - `minute_arbor`: under the 14t pinion + under the 80t wheel outside the
    pinion's footprint
  - `third_arbor`: under the 48t wheel (full annulus)
  - `fourth_arbor`: under the 8t pinion + under the 36t wheel outside the
    pinion's footprint
  - `escape_arbor`: under the 18t pinion (the trees also brace the tall post)
  - **Never** paint a ring that hovers ≤1 mm above the disc below it (wheel
    directly over its pinion) — no room to remove support; the slight sag
    self-heals and fuzz is fine. Collar steps ≤0.5 mm need nothing.
  - Anti-scar settings: top Z distance 0.2, top interface layers 2, top
    interface **spacing 0.4–0.5**, support/object XY distance 0.4,
    on-build-plate only. (A dense 0.2 interface WELDS into matted fuzz —
    proven on the first arbor batch. Loose interface peels as a sheet;
    the supported face only needs to be blob-free, not smooth.)
  - Put the arbors on their own plate — a toppled arbor shouldn't take the
    flat parts with it.
- **Cup-shaped parts print closed-face DOWN, mouth UP** (the drum: floor
  down). The interior — the surface the mainspring rides — then prints
  clean with zero support; auto-tree ≥50° catches only the outer gear-band
  ledge and cover lugs. Band-down buries the interior in support.
- Cleanup of supported faces: brass/nylon brush wheel in a rotary tool at
  the LOWEST speed (PLA melts at dremel speeds), or a knife scrape.
  Stay off tooth flanks.
- Print the **spares** the manifest calls for. Small gears are cheap and
  bench tuning consumes escape wheels and forks.

**Class C — flexures & grips (PETG ONLY** — PLA creeps and snaps here)
`mainspring`, `hairspring`, `click`, `transfer_pinion`, `stem_clip`
- PETG-HF: nozzle ~250 °C, bed 70 °C, **cooling 50%** (PETG wants less than
  PLA), 0.12 mm layers.
- Hairspring is a 0.45 mm single-line wall — do a flow calibration first;
  print 3, keep the best.
- Mainspring: 100% infill, flat as-printed spiral; print 2 spares.

**Class D — register pins** (`center_post`, `arbor_post_*`, `balance_staff`)
- Printable in PLA vertical, but these are the parts to swap for **metal**:
  Ø3 and Ø2 steel rod / dowel pin cut to length. The bores are sized for a
  press fit either way. This is the cheapest "feels like a real movement"
  upgrade.

## First-print sequence (recommended)

1. **`mainplate.stl` alone** — longest print; go do other things.
   Measure it (calibration loop above) before printing anything that mates.
2. **`bridge_DRAFT.stl`** + the barrel group (`drum`, `drum_cover`,
   `barrel_arbor`, `ratchet`, `crown_wheel`, `crown_stud`) on one plate.
   Fit the bridge to the measured mainplate — check the four pillars seat
   and the stem tunnel lines up.
3. Train arbors + escapement set (with spares).
4. Balance group + dial-side gears + platform + feet.
5. PETG parts (Class C) once your PETG spool arrives.

Hold the final **wave bridge** and the **decorated balance cock** — the
decorative pass replaces those; `bridge_DRAFT` is only to prove the fit.

## Hardware (not printed — from the manifest)

M3×18 ×6 + nuts (bridge pillars, cock feet), M3×20 ×3 + nuts (stand feet),
M2 self-tap ×6 (strap, click, platform), Super Lube (PTFE grease) on every
pivot before assembly. *(An earlier revision said M3×8 — too short to reach
the dial-side nut pockets through the 17.7 mm stack.)*

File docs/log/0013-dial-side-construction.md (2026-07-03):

# 0013 — Dial-side construction corrected (Jon's 2824/NH35 anatomy check)

2e as first committed floated the motion works in 7.4mm of open air
under the plate. Real construction (Jon's correction, confirmed):

- Motion + moon works sit in SHALLOW RECESSES pocketed into the plate's
  dial face; wheels are thin; axial confinement comes from recess floors
  plus a retaining platform (the date-platform analog — ours doubles as
  the moon guard). Only the hour wheel stands proud (2824-style), kept
  honest by a dial-washer analog (printed wave washer).
- Target dial-side protrusion beyond the plate face: <= 2mm print,
  ~0.8mm metal — variant tables, heights derived.
- Mainplate thickens (4 -> ~6.5) to host pockets below and bushings
  above; every assembly z that assumed plate_t=4 must derive from a
  single PLATE_T constant during the rework (they are hardcoded today —
  that is the real cost of this fix, and worth paying once).
- Optional later: dial-side windowing for a skeleton dial.

Sequence: 2e-r (this rework) -> 2e-half (rev B train/escapement part
ports) -> 2f (bridge beauty pass). Marked as the next session's opener.

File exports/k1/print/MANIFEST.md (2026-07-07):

# Caliber K1 rev C — print kit (movement r6)

## Hardware (not printed)

- **M3 + nuts** (hex nuts drop into dial-side pockets, 2.4 deep): **M3×18 ×6**
  (bridge pillars ×4, cock feet ×2 — stack is 17.7 minus the pocket) and
  **M3×20 ×3** (stand feet — plate 6.5 + foot 14). *An earlier note said
  M3×8 ×7 — that was wrong; ×8 doesn't reach any nut in this stack.*
- **M2 self-tap ×6** (bay strap ×2, click ×1, dial platform ×3).
- Super Lube (PTFE grease) on every pivot at assembly.

## Print profiles (Bambu Studio; 0.4 nozzle, textured PEI)

| class | parts | settings |
|---|---|---|
| **A** — big flats | mainplate, bridge_wave, dial_platform, dial_sheet | 0.20 layers, 20% gyroid (bridge_wave 100%), walls 4/4/4, brim 5 |
| **B** — gears, arbors, small | everything not listed elsewhere | 0.12 layers, 4 walls, **100% infill**, outer wall 50 mm/s, first layer 220°/rest 215°, bed 55° |
| **C** — flexures | mainspring, hairspring, click, transfer_pinion, stem_clip | **PETG** (Bambu PETG HF profile), 0.12 layers, 4 walls |
| **D** — register pins | center_post, arbor_post_*, balance_staff | PLA vertical, or swap for Ø3/Ø2 steel rod (press-fit either way) |

**Supports — the anti-scar recipe (learned the hard way on the first arbor batch):**
Tree (**manual**), painted ONLY where a row below says so. Top Z distance **0.2**,
top interface layers **2**, top interface **spacing 0.4–0.5** (a dense 0.2 interface
WELDS to the part), support/object XY distance **0.4**, on build plate only.
Never support a ring hovering ≤1 mm above the disc below it — no room to remove;
the sag self-heals. Cup-shaped parts print closed-face DOWN so the interior
needs no support at all.

**Brim:** type *Outer brim only*, width 5, gap 0.1 — on every vertical part and
the Class A flats. **Elephant-foot compensation ≥0.15** on; deburr and dry-fit
every plate-end pivot in its bushing before assembly (0.2 mm running clearance
is the whole budget).

## Parts

| part | qty | cls | orientation / supports |
|---|---|---|---|
| mainplate | 1 | A | dial face DOWN; tree supports in the dial pockets only. **Measure it before printing mates:** bushing Ø3.0, center bore Ø3.2, barrel recess Ø58.0, thickness 6.5 → set X-Y hole comp to the shortfall |
| drum | 1 | B | **floor DOWN, cup mouth UP** — the interior (where the spring rides) prints clean with zero support; auto-tree ≥50° catches the outside gear-band ledge + 3 cover lugs. *(Band-down buries the interior in support — don't.)* |
| drum_cover | 1 | B | flat, either face |
| barrel_arbor | 1 | B | vertical, square end UP; brim |
| mainspring | 1 | C | **PETG ONLY** — flat spiral as printed, 100% infill; print 2 spares |
| ratchet | 1 | B | flat |
| click | 1 | C | PETG preferred (PLA short-term OK); flat, pegs UP |
| crown_wheel | 1 | B | slots UP (top face down) |
| crown_stud | 1 | B | head DOWN |
| stem_and_crown | 1 | B | crown face DOWN, axis vertical; paint supports under the pinion |
| stem_clip | 1 | C | PETG preferred; flat; print 3 |
| minute_arbor | 2 | B | vertical, **long dial stub DOWN** (its tip is the one non-bearing end — it eats the elephant foot); brim. Paint under the 14t pinion + under the 80t wheel *outside the pinion's footprint*; skip the ring directly over the pinion |
| third_arbor | 2 | B | vertical, long lower pivot DOWN (48t wheel low, 8t pinion up top); brim. Paint the full annulus under the 48t wheel only |
| fourth_arbor | 2 | B | vertical, long pivot DOWN; brim. Paint under the 8t pinion + under the 36t wheel outside the pinion footprint |
| escape_arbor | 2 | B | vertical, bay pivot DOWN; brim. Paint under the 18t pinion — the trees double as bracing for the tall post |
| escape_wheel | 3 | B | flat (bench tuning consumes them) |
| pallet_fork | 3 | B | body flat, **long (2.0) pivot DOWN** — the body hovers 2 mm on the pivot tip. Paint the ENTIRE body underside; never the pivot. Peel supports away from the pivot, holding the body |
| bay_strap | 2 | B | flat |
| roller | 2 | B | flat, crescent side down |
| balance_staff | 1 | D | vertical; or cut from Ø3 steel rod |
| balance_wheel | 1 | B | flat |
| hairspring | 1 | C | **PETG ONLY** — flat; 0.45 walls = single-line: tune flow first; print 3 spares |
| balance_cock | 1 | B | arm flat, columns UP; paint supports under the stud post |
| stand_foot | 3 | B | vertical |
| center_post | 1 | D | vertical; or Ø3 steel rod |
| cannon | 1 | B | pipe vertical, hand-seat UP |
| hour_wheel | 1 | B | pipe vertical |
| motion_arbor | 1 | B | vertical |
| moon_w1 | 1 | B | flat |
| moon_w2 | 1 | B | vertical shaft |
| moon_disc | 1 | B | moons DOWN (two-color swap at 0.3 if using AMS) |
| transfer_pinion | 1 | C | PETG preferred; flat; slit collet is the hand-setting slip; print 2 |
| transfer_idler | 2 | B | flat |
| dial_platform | 1 | A | flat, proud face down |
| dial_sheet | 1 | A | face color! face DOWN; engraved markers paint-fill at the bench |
| minute_hand | 2 | B | hand color; flat |
| hour_hand | 2 | B | hand color; flat |
| bridge_wave | 1 | A | show face — pick a color! SHOW FACE DOWN (pillars up); 100% infill; supports only in the ratchet pocket + stem tunnel; brim |
| arbor_post_motion | 1 | D | vertical; or Ø2 steel pin |
| arbor_post_w1 | 1 | D | vertical; or Ø2 steel pin |
| arbor_post_w2 | 1 | D | vertical; or Ø2 steel pin |
| arbor_post_disc | 1 | D | vertical; or Ø2 steel pin |
| arbor_post_i1 | 1 | D | vertical; or Ø2 steel pin |
| arbor_post_i2 | 1 | D | vertical; or Ø2 steel pin |

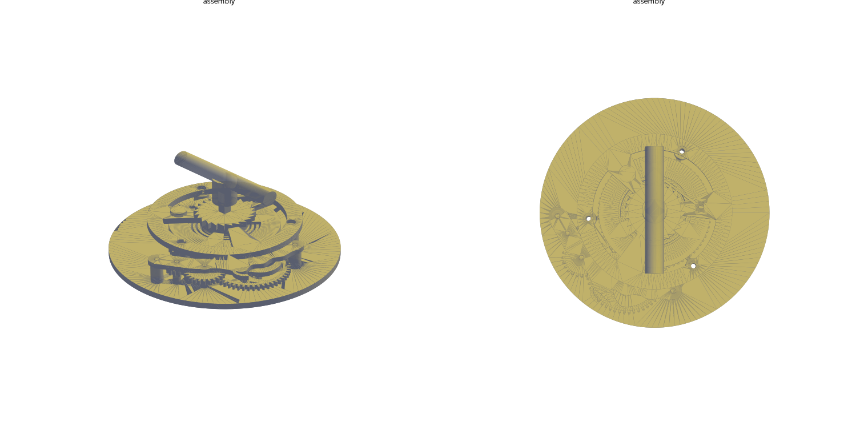
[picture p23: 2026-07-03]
docs/images/m2-assembly.png

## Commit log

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2026-07-03 Milestone 2: going train with cycloidal gears and the wave bridge
    - gears.py: cycloidal profile generator (epicycloid wheels, radial-flank
    pinions) — the horologically correct form for 12-16 leaf pinions
    - Train: 72/16 x 50/12 x 24/12 gives an exact 60.0000s seconds arbor and
    60 min design runtime from 3.2 spring turns; drum gains its 72t ring gear
    - decor.py: ocean design language — wave-crest train bridge (chaikin-
    smoothed spine, gaussian swells, log-spiral curl) + whirlpool wheel spokes
    - Layout folded into the pillar gap at az 245.7deg; pairwise clearances
    tested (caught a rim overrun and a bridge/pillar sweep during design)
    - Fix: M1 pillar generator produced two coincident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
2026-07-03 Wave bridge crest v2: the tube is the wave
    Design review feedback: the log-spiral lip read as a fragile snap-off
    tab. Rebuilt the crest as a solid forward-leaning lobe with the tube
    carved out as an OPEN round hollow — the lip now tapers over the mouth
    like a closing-out wave. Swells unchanged. Crest shifted to 0.40 along
    the spine to keep the mouth clear of the W4 bearing boss.
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2026-07-03 Milestone 3: pin-pallet escapement, 1 Hz balance, the jewel in the wave
    Escapement storey above the wave bridge: 30-tooth escape wheel, pin-pallet
    lever (FDM-tolerant), Ø50 balance on an 11-coil printed PLA hairspring
    (predicted T=1.037s, trimmed via rim nuts), balance cock with a functional
    4mm cabochon cap jewel centered over the wave tube. Plate grows to Ø170.
    27 geometry tests incl. oscillator physics band and full clearance sweeps.
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2026-07-03 Milestone 4 geometry: motion works, deck plate, dial cock, hands, knob
    Ten new parts on the locked layout: climbing R1, deck R2, dial-center T
    with cannon and tube, M arbor, loose hour wheel, deck plate, dial cock,
    low-profile winding knob (T-handle retired), minute + hour hands. W1
    gains its takeoff pinion. v0.1 sets time with the drum locked.
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2026-07-03 Rev B step 1a: dual-train arithmetic — identical wheels, one movement
    Metal and print variants share the classic layout (center wheel exactly
    60 min AT CENTER, fourth 60s, escape 30s @ 1Hz): the print variant pays
    for plastic torque with a thicker, shorter spring (1.5 turns x 8h = 12h
    runtime) instead of a bastardized train. Geometry stays CNC-honest.
2026-07-03 Rev B step 1b: flat train layout — 6 stations, 2 gear planes, 24mm stack
    Center wheel at origin (hands at center), barrel offset az105, train
    arcs clockwise to the escapement, balance at (-24.8,-42.8) where the
    wave bridge's tube will crown it. All meshes exact, same-plane wheel
    clearances proven, everything inside the Ø170 rim.
2026-07-03 Rev B fix-forward: barrel 72t at r42 (rim-legal), 6h/rev, center still 60min
    The 96t offset barrel reached r103 — impossible on a Ø170 plate. The
    existing Ø72 drum's ring gear gives 6h/rev: center stays exactly 60min,
    metal reserve 42h (7 turns), print 9h. Also: never pipe pytest before
    &&-chaining a commit — the failing exit code got swallowed.
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2026-07-03 Broad wave bridge WIP: mechanics pass, art fails — defects on record
    Structure verified by test: five open bearings, balance well swims the
    ring with even margin, barrel arbor bearing in-plate, feet clear. Art
    self-review against the render: (1) swells illegible — absorbed by the
    structural pads; (2) the curl's tube landed as a stray porthole SE of
    the well instead of cresting at its rim; (3) the wave band reads as
    decoration glued to a blob, not the plate's own edge. Fix plan: the
    wave band must BE the outboard boundary; crest placed so the well cut
    opens the curl's mouth; swells scaled to the plate, not the band.
    [wave_bridge.step]
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2026-07-03 Rim containment fix + keyless works layout (step 2d begins)
    New test caught the bridge outline overhanging the mainplate rim by
    ~10mm at the north edge — outline pulled in, barrel plateau rim-flush,
    review assembly re-exported. Keyless layout locked: stem at az105/z26.25
    aimed at the barrel arbor, face-gear crown wheel meshing the 24t ratchet
    above the bridge, all inside the reserved sector. Setting via friction
    cannon lands in 2e.
    [review_2c_assembly.step, wave_bridge.step]
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2026-07-03 Stem fix: pinion re-seated over the crown wheel's slot ring (was 10mm deep)
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2026-07-03 Click v2: Jon's catch — tip floated 2.9mm short of the teeth
    Rebuilt in the ratchet frame with M1's proven jamming geometry scaled
    to the 24t wheel: wedge tip at r12.1 (0.9 into the teeth), tangential
    arm so CCW loads the arm axis and digs in, CW rides over. Click and
    bridge peg holes now derive from ONE shared geometry function, and a
    new test asserts the tip actually lands inside the tooth band.
2026-07-03 Click v2 landed: engaged, tested against the built part, holes derived
    Prior commit shipped the old floating click (patch script died on a
    missing end-marker; the new test only validated the spec dict). Now the
    part builds from the shared outline, bridge holes come from
    click_peg_points_global(), and a boolean placement test proves the
    BUILT part engages the tooth band (1.65mm3 measured, >1.0 required).
    Lesson banked: 'does X work' tests must exercise the artifact, not
    its spec.
2026-07-03 Crown outboard (r88) + knob/bridge clearance test; deviation register
    Jon triple-checked the stem height: the line is high because it must
    overfly the 20.5mm printed drum (metal variant sits at plate level —
    now in the deviation register). His eye also flagged real crowding:
    the knob's inner face was within ~1mm of the bridge's north edge.
    Crown now overhangs the plate edge like a real watch crown.
2026-07-03 The variant switch: print and metal as one geometry, two tables
    Jon's requirement: flip between printable prototype and CNC-ready metal
    without starting over. Foundation: Variant dataclass (drum height,
    clearances, spring, escapement), K1_VARIANT env switch, and the first
    derived dimension — the stem line as a formula that yields 29.5 on the
    tall PETG drum and ~16 on a 4.5mm steel barrel. Tests pin both worlds
    to one layout so geometry cannot fork by accident.
2026-07-03 Rev B step 2e: dial side — motion works + moon train, born variant-aware
    Cannon (friction slot), minute wheel with the classic module trick
    (36t@m1.0 to the cannon, 10t@m0.96 to the hour wheel — both meshes at
    exactly 24mm), hour wheel with integral 14t moon pinion, s1, and the
    Ø64 moon disc tucked SW clear of the center pipes. All dial-side bores
    draw clearances from active_variant(). 52 tests green.
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2026-07-03 Full-movement review r2 + sealed-bushing fix, independently verified
    Jon's 'show me the whole movement' exposed that the plate thickening
    had sealed all six bridge-side bushings inside solid material — they
    now cut from the top face, with an entry-probe test. New versioned
    one-file review (review_full_movement_r2.step, 25 components: all real
    parts both sides + labeled placeholders for the 2e-half ports).
    Verification workflow: STEP re-imports clean (26 solids), moon window
    open at the aperture (0.000mm3 with negative control), all bushings
    admit pins, and git forensics confirms the user's Fusion upload
    predated the moon-window commit by ~1 hour (stale file, not a bad fix).
    Co-Authored-By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
2026-07-04 The train is real and it meshes: kinematic fix + phase-aligned proof
    The adversarial probe caught three compounding defects: (1) the Ø66
    center wheel sat 27mm inside the tall drum's body — hoisted to a
    variant-derived plane above the drum top, bridge follows; (2) the
    center-third distance created an accidental second mesh (60t wheel
    against 12t pinion, ratio 5 vs intended 8) that would jam the train
    solid — tooth counts retuned to 80/8 -> 48/8, still exactly 60.000 min
    and 60.000 s, layout distances now DERIVED from counts; (3) cycloid
    flanks self-crossed on 8-leaf mates — capped at the tooth midline, plus
    BS978-style 0.85 addenda and 0.3 backlash. The probe itself needed
    fixing too: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
2026-07-04 Status correction: no lever in r6 — escapement port is the open item
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2026-07-04 The Swiss lever locks AND releases: clock-span anchor, probe-proven
    Probe-caught corrections: watch-span hub sat inside the wheel rim
    (-> 6.5-space clock span, Laimer's reason); banana arms arc the rim;
    stones dip 1.2mm inside the tip circle (on-circle grazed at zero); and
    the release window is ~2 deg wide drifting with phase, so the test
    probes the joint (phase x swing) grid: deep lock somewhere (>4mm3),
    free wheel somewhere (<0.5). Variant angles: print 3/15, metal 1.5/13.
    The movement now has every organ, in both material worlds.
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2026-07-04 Removable pallet bridge cassette; stilted relic retired (Jon's catch)
    Jon spotted the long-shafted, mispositioned pallet mount in r7 — the
    obsolete 2c pin-pallet cock on press-fit stilts, still in the build at
    the OLD pallet position. Replaced with the architecture he specified
    from the bench: a U-cassette pallet bridge bearing the fork's SHORT
    (5.8mm) integral arbor above and below, on two M3-screwed columns —
    remove two screws, lift the fork, service the balance. Plate gains
    screw holes + dial-side nut pockets. Review r8: no relics.
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2026-07-04 Balance lifted over the wave (Jon's collision catch + composition win)
    The Ø50 ring shared a 2mm z-band with the hoisted 80t center wheel —
    21.7mm radial overlap, unguarded by any test. Jon's fix restores the
    original composition: ring now rides 0.5 over the broad bridge's top,
    jewel on display above the wave, the well framing the staff below.
    Cock risers grow to 10.7; staff rod to 50mm; new test enforces the
    ring/center-wheel z gap forever. Review r11.
2026-07-04 Balance in the well, under the bridge — Jon's placement, properly this time
    I misread the prior direction and top-hatted the ring above the bridge.
    Correct home per Jon's arrow: between plate and bridge, visible through
    the well. Made true by numbers: pallet strap thinned to 1.5 (top 23.7),
    high center wheel lifted +0.7 — ring rides 24.3-29.3 with 0.6/0.7
    margins; hairspring + short-riser cock float above the well. Guard test
    enforces the sandwich. Metal oscillator placement flagged for DFM.
    Review r12.
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2026-07-04 Rev C: a feasible FLAT layout, found by whole-movement solve
    The expert brief executed: swept-volume model + global collision gate
    written FIRST; mesh pairs whitelisted (probes govern engagement); drum
    slim-walled and recessed into the plate; the big wheel moved to the
    clear plane; minute display made indirect (1:1 dial-side transfer) so
    the train packs freely. Result: barrel/minute/third/fourth/escape/
    balance all legal at max reach 79 of rim 83, TWO gear planes + one
    escapement plane, cock tops at 28.7 vs rev B's 53.6 — the stack nearly
    halves. 4h/rev drum -> ~18h runtime. Frozen as REVC_LAYOUT with the
    global gate test rev A and rev B never had.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
2026-07-04 Rev C v2: balance ON the plate — 20.5mm flat, solver-proven
    Jon's massing note executed the expert way: two structural binders
    found by arithmetic (escape wheel vs fourth arbor at plane A -> fourth/
    escape enlarged to 36/18, ratio still exactly 2; ring vs escape pinion
    -> lever span 40) and the whole movement re-solved. Result: oscillator
    at plate level like every real watch, cock coplanar with the ONE
    bridge, stack 20.5mm over O170 (8:1 — better than watch-typical),
    max reach 69.4 of rim 83. Massing r2 for the composition gate.
    [massing_r2.step]
2026-07-04 rev C v3: escapement bay recessed into the plate, stack tops at 17.7
    Jon's massing r2 notes, all three implemented:
    - lever massed as its true envelope (hub r13 + fork r5 capsule), not a
    r19 blob engulfing the escape wheel; intra-escapement pairs whitelisted
    (one rigid mechanism — spacing owned by the escapement probe)
    - escapement bay recessed 2.5 into the plate (roller/lever/escape wheel
    z4.2-6.7); ring sits literally on the plate; bridge+cock coplanar at
    14.7-17.7 — the cock is no longer the tallest thing, NOTHING is taller
    than the single bridge plane. Constraint recorded: dial-side pockets
    must not share plan-area with the bay recess
    - clearance 2.0 everywhere (rim-room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
    [massing_r3.step]
2026-07-04 rev C parts port: full movement r1, adversarially verified
    Jon's massing gate passed -> every proven rev B generator re-derived
    onto REVC_LAYOUT. 19 components in exports/revc/movement_r1.step:
    plate (bay recess, cups, banking pins), hanging barrel (+ dial-side
    ratchet & click: holds wind, retains the arbor), 4 train arbors
    (minute through-bore = indirect-minute interface), club wheel, Swiss
    lever, bay strap (the rev C pallet cassette), true two-tier roller,
    staff/wheel/hairspring/cock, broad bridge (cock nestled, open to rim).
    69-agent adversarial review before human gate: 61 confirmed findings,
    ~20 unique defects fixed — the draft escapement was DOA three ways
    (banking pins pinched the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
2026-07-04 rev C dial side: solved face, 3-stage moon, transfer chain, r2 export
    Dial model+solver (revc_dial.py): four depth bands into the dial face,
    depth rules vs every bridge-side carving (0.6 web), frozen DIAL_LAYOUT
    at reach 64.3/83. Three derived theorems: 1:1 transfer must be an
    idler CHAIN (odd meshes keep hands clockwise; chirality documented);
    the hour pipe must be SHORT with the moon pinion low (axis theorem);
    a 2-stage moon train is geometrically impossible at the origin (rev B
    carried that collision silently) -> three stages (36/24)(54/12)(70/8)
    = 59.0625 exact, 29.53125d. Parts (revc_dial_parts.py) incl register
    pins, wheel-form idlers, module-scaled backlash, and the hand-setting
    frict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
2026-07-05 stem comes down to mid-height (Jon's NH35 section catch) — massing r6
    The pendant boss was a rev B printability leftover (face-slot mesh on
    TOP of the crown wheel costs a pinion-radius of height). NH35-true fix:
    the crown wheel gets a TALL CORE in a bridge seat — spur teeth up top
    meshing the ratchet, contrate teeth (radial slots, the printable bevel
    rotated 90 deg) down at stem level. Stem enters at z13.0 in the corridor
    between the drum gear band (the gate caught a 0.7mm graze and set the
    exact height) and the bridge, tunnel half in a bridge boss. Nothing
    above z17.7 anywhere. massing_r6, 81 tests green.
    [massing_r6.step]
2026-07-05 winding stage: stem, crown wheel (underside slots), stud, clip — r5
    6498-true: slots in the crown wheel's UNDERSIDE, pinion meshes from
    below; stem at z12.8, crown outside the rim at mid-height, nothing
    above the bridge. Slot ring spans the pinion tip chord (probe caught
    the short-slot graze; settled-roll profile 0 -> 1.4). Analytic
    drum-clearance test justifies the drum_gear x stem whitelist (2.85).
    Bridge: crown pocket, stud bore, tunnel boss + clip slot. Builder
    phases crown to the square-aligned ratchet, stem rolled to mesh.
    movement_r5 (40 components), 82 tests green. Log 0020.
2026-07-05 stem tunnel truly anchored (Jon's floating-block catch) — movement r6
    The tunnel boss only kissed the bridge's r79 edge by 1.6mm and read as
    floating. Fix chain, each step verified by boolean: bridge grows a rim
    TAB over the tunnel (behind the pinion — the first tab roofed its tip
    circle), the boss retreats behind the pinion, the clip slot aligns to
    the actual clip, and the web gains the WINDING-PINION WINDOW (the
    pinion reaches through to the crown wheel's underside slots — the
    first boss had been swallowing the pinion silently; stem x bridge and
    clip x bridge are now gated assembled pairs, both zero). 82 green.
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2026-07-05 print kit fully watertight: click rebuilt from primitives
    The click's one-polygon outline self-intersected at the flexure arm
    (introduced when the arm was pushed outside the tooth band) — OCCT
    skipped its top/bottom faces and the mesh leaked; the pallet fork
    leaked only at default mesh tolerance. Click now = block + swept band
    + wedge primitives (same tip bite, same pegs+M2); the bridge pocket
    derives from the same face; kit exports at 0.02 tolerance. All 41
    STLs verified watertight. 82 tests green.
    [arbor_post_disc.stl, balance_wheel.stl, bridge_DRAFT.stl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]
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2026-07-05 docs: FDM printing guide (Bambu, PLA/PETG per part class)
    Slicer settings by part class (flat plates / gears / flexures / register
    pins), the baked-in-clearance warning (don't stack hole compensation on
    the designed 0.20 pivot clearance), the mainplate-first calibration loop
    with verified target dims (train bore O3.0, minute bore O3.2, barrel
    recess O58.0, plate 6.5), and the recommended first-print sequence.
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2026-07-05 the THREE-BRIDGE wave (Jon's art direction, done properly)
    Jon's mock-up read correctly: the bridge layer is THREE separate
    plates — sky (crest), winding corner, sea (train) — whose gaps paint
    the wave, exactly like the NH35's own bridge partition. Curves are now
    real cubic Beziers (caliber_k1/wave_art.py: control points editable
    like Illustrator handles; SVG import offered as an alternative
    pipeline). SEP1/SEP2 are true rim-to-rim separations routed clear of
    every boss and pocket; the Hokusai curl and sea slots stay
    keepout-clipped. Two new screw posts so every plate has >=2 anchors
    (gated); pivot bosses proven whole on exactly one plate (gated);
    junction sliver killed. movement_r8.step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
    [bridge_sea.stl, bridge_sky.stl, bridge_winding.stl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]
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2026-07-05 print kit: one clean bridge_wave.stl (remove stale 3-plate STLs)
    The kit still tag-split the bridge into sky/sea/winding from the
    abandoned 3-plate era, mis-saving the single skeleton plate under the
    wrong name. Export one bridge_wave.stl (show face down, 4 pillars);
    delete the stale bridge_sky/sea/winding/DRAFT files.
    [bridge_DRAFT.stl, bridge_sea.stl, bridge_sky.stl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]
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2026-07-05 Caliber K2 is born: the metronome becomes its own movement (Jon's call)
    Two calibers, like a real manufacture: K1 stays the O170 moon-phase
    hand-wind clock EXACTLY as printed (module-bay placeholder removed —
    no reprint needed); K2 is the metronome on its own O140 plate, sharing
    K1's proven libraries. K2 v0 SOLVED (reach 57.1/66, 1s): basement drum
    (id66 x 2.6x7.0 strip = 6.7 J -> 6775 beats = 38 min @180 / 113 @60,
    target 5400 met), interleaved train planes, escapement on its own
    storey (both K1 theorems resurfaced and reapplied), variable-inertia
    balance at center stage, knob/pusher/anvil zones placed. Massing r1
    exported for Jon's gate. Tests: K2 gate + energy + gearing. 87 green.
    Co-A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
    [massing_r1.step]
2026-07-05 K2 corrected: TIME + metronome — a two-barrel, two-crown caliber
    Jon's clarification: K2 tells time too (K1 = time+moon, K2 =
    time+metronome). K2 now = K1's proven clock core VERBATIM (frozen
    coordinates, minus the moon train) + the metronome cluster as a
    rigid translatable/rotatable unit. Placement solver slides+rotates
    the cluster against the frozen clock under the joint gate: SOLVED at
    offset (88,-16) rot 90 in <1s. Plate = union of discs (clock r85 +
    metronome r66), 239 x 175 x 32.1 capsule; two winding stations
    (clock crown north, metronome ratchet+crown wheel on its own disc),
    tempo knob + pusher zones placed. massing_r2 (49 components) for
    Jon's gate. 88 tests green.
    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
    [massing_r2.step]
2026-07-05 K2 on ONE round plate (O216) — no frankenplate; one crown, TWO positions
    Jon's corrections applied: single circular plate (diameter free vs K1)
    and one crown with two winding POSITIONS (a real keyless works: the
    sliding clutch engages the clock ratchet in position 1, the metronome
    ratchet in position 2). The constraint had teeth: the met barrel must
    sit on the stem corridor, but two huge drums can't share a z-band —
    the K1 interleaving theorem at movement scale. The met cluster now
    rides a storey higher (drum 12-20.5 passes OVER the clock's plane B;
    b_arbor clearance verified), its barrel in the north corridor; the
    clock's private stem/crown wheel yield to the shared two-position
    corrido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
    [massing_r3.step]
2026-07-05 K2 massing r4: both drums SUNK, the crown drawn where Jon can see it
    Jon's catches on r3: no visible crown/stem (the corridor was anonymous
    zones), and the met barrel floated at z12+. Fixes: the met drum sinks
    into a K1-style recess (z2.2-11) in the virgin northern plate — the
    whole met stack drops from 37.1 to 29.2; the winding line is now REAL
    geometry in the gate: stem cans from the NE rim to the clutch, crown
    outside the rim, cw1 tall-core (position 1 -> clock ratchet), cw2 +
    transfer idler (position 2 -> met ratchet), all along one stem line
    derived from the two arbors. The crown was inflating the plate radius
    (it lives OUTSIDE the rim, like K1's) — excluded, and the solve
    converged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
    [massing_r4.step]
2026-07-06 K2 flat: joint free-station solve — O250 round plate, 17.7 stack
    Jon's 'go down, not just up' + the floating m_knob_line catch led to
    the real fix: the met cluster adopts K1's z-grammar verbatim (sunken
    drum, bay escapement, plate-level balance) — which exposed that the
    rigid v0 cluster was internally impossible flat (21mm barrel-escape
    spacing vs 50.5 needed once the escape wheel shares z with the drum).
    Cluster dissolved: the joint solver places the met stations FREE among
    the clock's (720s, step 12/6). Result beats the stacked design on both
    axes: O250 x 17.7 vs O252 x 27.6. Furniture re-anchored from frozen
    stations to the real rim (knob line, pusher — rim furniture, exempted
    like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
    [barrel+winding-group-k1.3mf, massing_r5.step]
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2026-07-06 K2 winding link position 2 SOLVED: one crown, cross-plate to the module
    The hard part of the one-crown-two-position winding: reaching the module
    barrel on the far plate. solve_winding_link searches the riser azimuth
    for a channel clear of both drums; first minimized plate reach (threaded
    70mm up the south channel - valid but absurd), re-aimed at shortest
    winding path -> NE flank, 44.5mm: crown ~2 o'clock -> riser up the drum
    flank -> transfer -> module crown wheel -> module ratchet. Clean vs both
    plates. Keyless cluster (clutch/setting/detent/riser) whitelisted as one
    interlocking mechanism. Position 1 (base barrel from the same crown,
    dodging K1's click) is ordinary keyless routing, left ho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
    [two_sided_r2.step]
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2026-07-07 manufacture layout, phase 1: docs + exports namespaced per caliber
    The repo is a two-caliber manufacture now (renamed: kelsus-manufacture);
    the tree starts reading that way:
    - docs/k1/ takes the K1-specific docs (printing guide, milestones,
    escapement register, wave docs, interface contract); docs/log/ stays
    UNIFIED — it's the build-in-public journal, K2 entries interleave
    - fix the duplicate log number: 0020-winding-stage -> 0019b (it predates
    the metronome brief, which external references know as log 0020)
    - docs/img merged into docs/images
    - exports/k1/{print,revb,revc} + exports/k2; review STEPs pruned to the
    latest per line (r-history lives in git)
    - exports/k1/print/plates/: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
    [arbor_post_disc.stl, arbor_post_i1.stl, arbor_post_i2.stl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]
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
